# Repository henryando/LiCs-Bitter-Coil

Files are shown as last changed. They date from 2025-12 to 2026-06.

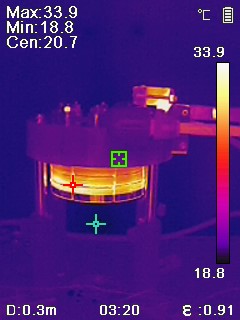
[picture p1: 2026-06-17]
ThermalImages/2026-03-30 New C1/IMG20260330032043.jpeg

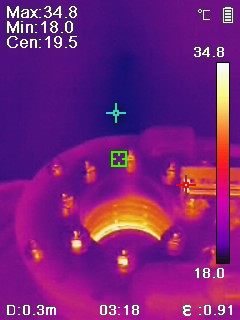
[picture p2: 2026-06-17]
ThermalImages/2026-03-30 New C1/IMG20260330031851.jpeg

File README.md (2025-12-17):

# LiCs-Bitter-Coil
Design files and instructions for Bitter coils built in the LiCs experiment in Chin Lab @ UChicago. 

The key authors of the files in this repository are Henry Ando, Leon Gold, and Cheng Chin. This repository is intended as an informational resource for the cold atom community. At the moment, it contains the following:

1. A PDF assembly guide written by Leon Gold, which outlines the key steps in our assembly process.
2. A folder containing all the CAD files for the coil we built. We designed it in Autodesk Fusion 360, so the 3D files are in that format. I have also included minimal 2D drawings, which are mostly for reference.
3. A draft of a manuscript describing the more general improvements we plan to make.

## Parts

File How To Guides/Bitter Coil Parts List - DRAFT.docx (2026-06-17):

# NEEDS UPDATE

# Full parts list

## Coil stack

- Bottom CuCr Disk x1
  - Machined by 3ERP out of C182 (CuCr alloy)
  - Immediately before assembly, cleaned with hot acetic acid
- Copper discs (normal) x30
  - Waterjet in house
  - From 0.04" thick 101 copper sheet, PN 89675K736 (https://www.mcmaster.com/89675K736)
  - Sanded with grits 220, 400, 600, 1200, 2000
  - Immediately before assembly, cleaned with hot acetic acid
- Copper disc (top) x1
  - Waterjet in house
  - From 0.04" thick 101 copper sheet, PN 89675K736 (https://www.mcmaster.com/89675K736)
  - Sanded with grits 220, 400, 600, 1200, 2000
  - Immediately before assembly, cleaned with hot acetic acid
- Copper connecting wedges x31
  - Waterjet in house
  - Leave tabs so they don’t fall off
  - Sandwich between two sheets of aluminum (89015K37 (https://www.mcmaster.com/89015K37)) so they don't completely warp, then use the thickness of the resulting sandwich in the waterjet settings
  - File off the tabs with the file side to side, i.e. along the axis of the tab, slowly and gently.
  - Made from 9014K174 (https://www.mcmaster.com/9014K174/), the shim stock is important because it has a much better thickness tolerance.
  - Sanded with grits 600, 1200, 2000. Sand lightly so you don't wear down the thickness too much.
  - Immediately before assembly, cleaned with hot acetic acid
- Polyester spacers x31
  - Laser cut in house
  - From 0.01" thick brown shim stock, PN 9513K119 (https://www.mcmaster.com/9513K119)
  - Use the PETG setting, 0.01" thick on the laser cutter
- Polyester spacer top x1
  - Laser cut in housee
  - From 0.01" thick brown shim stock, PN 9513K119 (https://www.mcmaster.com/9513K119)
  - Use the PETG setting, 0.01" thick on the laser cutter
- Silicone banana gaskets x94
  - Laser cut in house
  - From 0.02" thick high-temperature silicon rubber strips, durometer 40A (medium soft), PN 5344N113 (https://www.mcmaster.com/5344N113)
  - Use the silicone setting, 0.02" thick on the laser cutter
  - Note that the silicone pieces tend to fly away due to exhaust wind!
  - After cutting, sonicate in water then rinse in a strainer
- Silicone circle gaskets x64
  - Laser cut in house
  - From 0.02" thick high-temperature silicon rubber strips, durometer 40A (medium soft), PN 5344N113 (https://www.mcmaster.com/5344N113)
  - Use the silicone setting, 0.02" thick on the laser cutter
  - Note that the silicone pieces tend to fly away due to exhaust wind!
  - After cutting, sonicate in water then rinse in a strainer

## Compression screw system

- Stainless steel compression screw x7
  - Machined by 3ERP out of 316 stainless steel
- CuCr Screw x1
  - Machined by 3ERP out of C182 (CuCr alloy)
  - Path: RevisedManufacturing20231107/MachineParts/Steel-Compression-Rod.step
  - Immediately before assembly, cleaned with hot acetic acid. I think sanding will only hurt, the surface finish from 3ERP rocks
  - Note for future: make the groove in the top a bit deeper and/or make something stick off the top that you can grab with a wrench, the slot I milled this time is a bit thin and wore out quick under stress.
- O-rings x8
  - Chemical-Resistant Viton® Fluoroelastomer O-Ring 1/8 Fractional Width, Dash Number 202, PN 9464K118 (https://www.mcmaster.com/9464K118)
- Top washers (many, at least 24)
  - 316 Stainless Steel Washer for 1/4" Screw Size, 0.281" ID, 0.625" OD, PN 90107A029 (https://www.mcmaster.com/90107A029)
- Nuts for top of steel screws
  - 316 Stainless Steel Hex Nut, 1/4"-28 Thread Size, 94804A305 (https://www.mcmaster.com/94804A305)
- Nut for CuCr screw x1
  - 316 Stainless Steel Thin Hex Nut, Super-Corrosion-Resistant, 5/16"-24 Thread Size, 94805A213 (https://www.mcmaster.com/94805A213)
- Washers for CuCr screw (at least 3-4)
  - 316 Stainless Steel Washer for 5/16" Screw Size, 0.344" ID, 0.75" OD, 90107A030 (https://www.mcmaster.com/90107A030)

## 3D printed piece & water system

- 3D printed piece
  - Printed in SLA "High Temperature Resin" by a company we found through CraftCloud, called 3DPnxt
  - OR maybe printed in SLA "Surgical Guide Resin" this is the recommendation from Shaozhen!
- NPT tap
- Vibra-TITE 481 Plastic Thread Sealant 70 mL (https://www.amazon.com/gp/product/B09GWBD2XG/)
- Plastic NPT to push-to-connect fitting (https://www.usplastic.com/catalog/item.aspx?itemid=30737)
- Vacuum chamber screws
  - Ours are probably 1/4-20 or 1/4-28

## Bus bar system

- Bus bar top
  - C101
  - Machined by 3ERP
  - Immediately before assembly, cleaned with hot acetic acid
- Bus bar bottom
  - C101
  - Machined by 3ERP
  - Immediately before assembly, cleaned with hot acetic acid
- Top bus bar bracket
  - Machined by 3ERP
- CuCr screw
  - Machined by 3ERP
- Plastic separator x1
  - Laser cut in house
  - 0.01" brown plastic shim stock
- O ring x1
  - Chemical-Resistant Viton® Fluoroelastomer O-Ring, 3/32 Fractional Width, Dash Number 108
  - 9464K113 (https://www.mcmaster.com/9464K113)
  - Note this is DIFFERENT than the other ones
- Tube fittings x2
  - Push-to-Connect Tube Fitting for Air and Water, Nickel-Plated Adapter, for 1/4" Tube OD, 1/16 NPT Male
  - 7880T123 (https://www.mcmaster.com/7880T123)
- Countersunk 2-56 nylon screws, 3/4" long, x2
  - PN 92929A120 (https://www.mcmaster.com/92929A120)
- Simple 2-56 nylon screws, 1" long, x6
  - 94613A086 (https://www.mcmaster.com/94613A086)
- Bus bar mounting screws: 6-32, 7/8" long, x6
  - 92185A152 (https://www.mcmaster.com/92185A152)
- Top bus bar bracket screws x2
  - 1-1/8" long, 316 stainless steel
  - PN 92185A154 (https://www.mcmaster.com/92185A154)
- Bottom bus bar bracket screws x2
  - 1-5/8" long, 316 stainless steel
  - PN 92185A174 (https://www.mcmaster.com/92185A174)
- Lug screws
  - 1/4"-20 Thread Size, 1/2" Long
  - PN 93190A537 (https://www.mcmaster.com/93190A537)
- Lug washers
  - 1/4" washers

## Assembly props

- Steel dowels 1/4" x 3"
  - PN 98381A554 (https://www.mcmaster.com/98381A554)
- Clamp jaws, top and bottom
  - Make out of random scrap from machine shop
  - Or ask DeMille lab to borrow?

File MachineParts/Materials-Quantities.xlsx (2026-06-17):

Part | Material | Quantity
Bus-Bar-Bottom.step | C101 | 2
Bus-Bar-Top.step | C101 | 2
CuCr-Compression-Rod.step | C182 | 2
CuCr-Disk.step | C182 | 2
CuCr-Rod-Bracket-A.step | C360 | 2
CuCr-Rod-Bracket-B.step | C360 | 2
Steel-Compression-Rod.step | SS316 | 15
Top-Layer-Bracket.step | C360 | 2

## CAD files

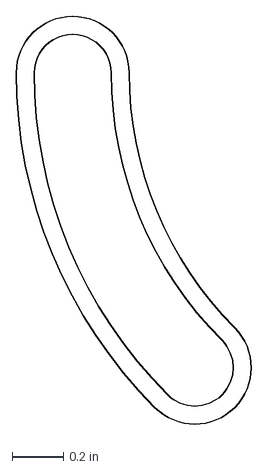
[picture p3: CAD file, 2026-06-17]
LasercutParts/Modified-Banana-Gasket.dxf
0.937 x 1.61 in

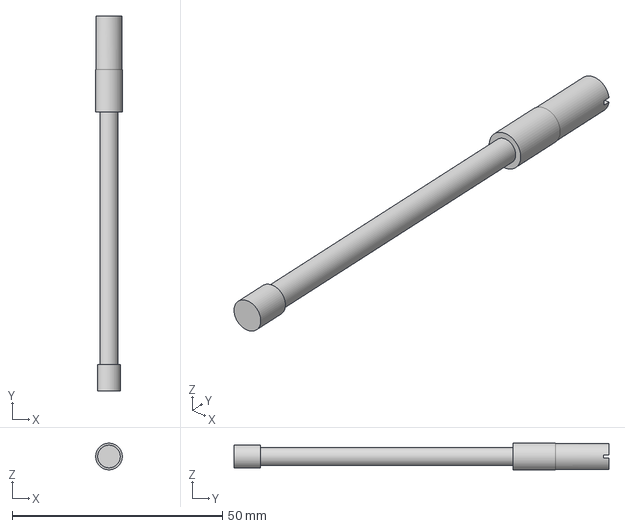
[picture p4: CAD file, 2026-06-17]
MachineParts/Steel-Compression-Rod.step
6.34 x 89.2 x 6.35 mm

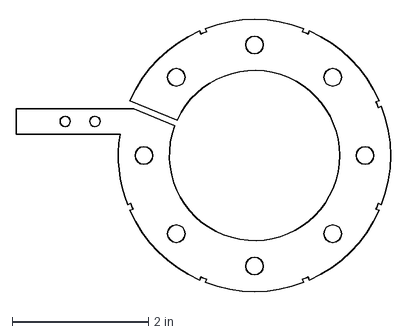
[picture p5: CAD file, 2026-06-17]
WaterjetParts/Copper-Disc-Top-2025mod.dxf
5.55 x 4.09 in

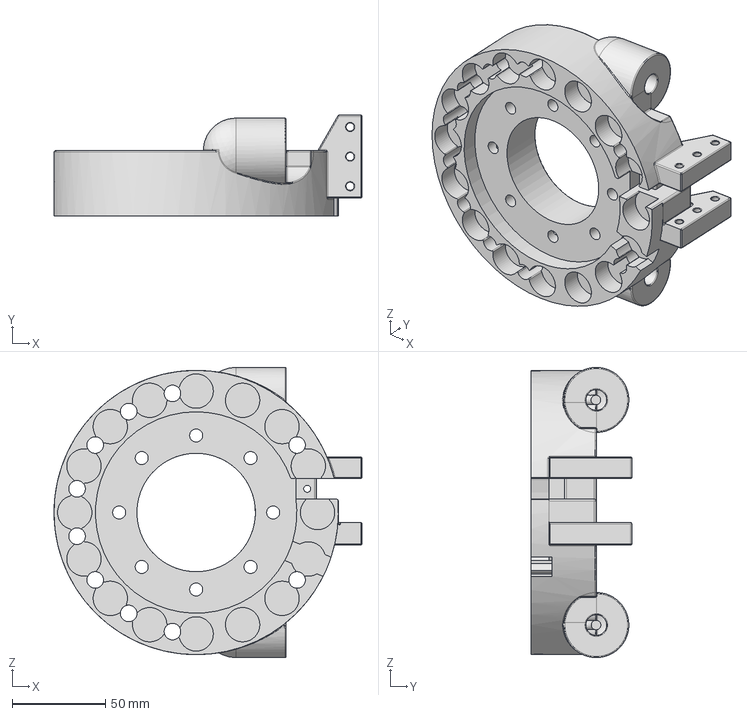
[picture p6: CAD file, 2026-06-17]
3DPrintedParts/Water-Distribution-Block v30.step
165.1 x 54.0 x 155.6 mm

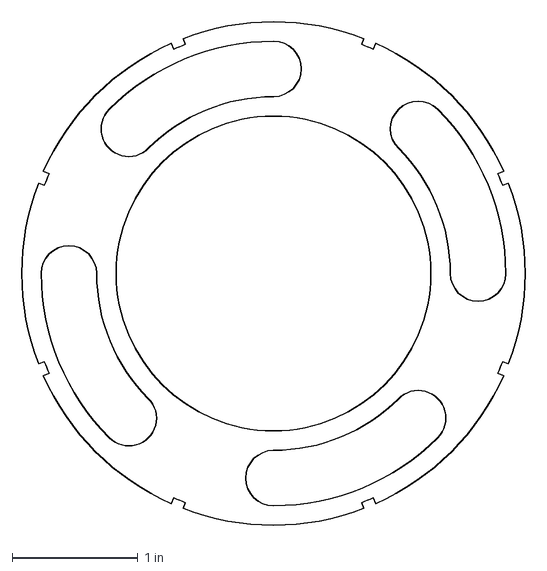
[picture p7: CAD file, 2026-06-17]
LasercutParts/Modified-Poly-Spacer-Top.dxf
4.09 x 4.09 in

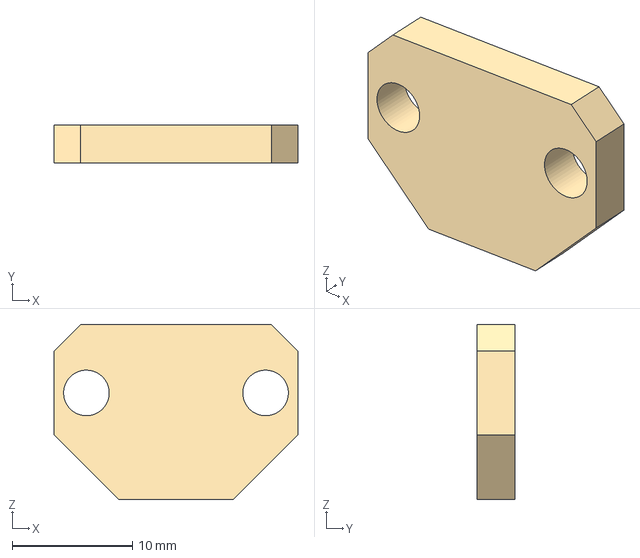
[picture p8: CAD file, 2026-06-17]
MachineParts/CuCr-Rod-Bracket-B.step
20.3 x 3.17 x 14.6 mm

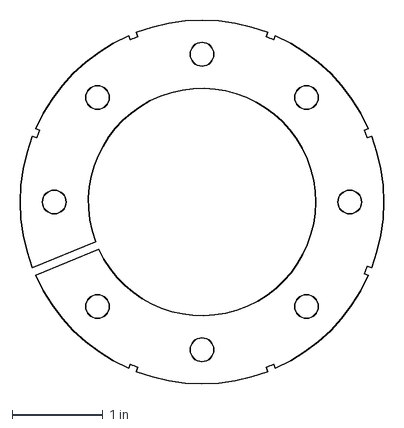
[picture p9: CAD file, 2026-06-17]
WaterjetParts/Copper-Disc-Layer.dxf
4.09 x 4.09 in

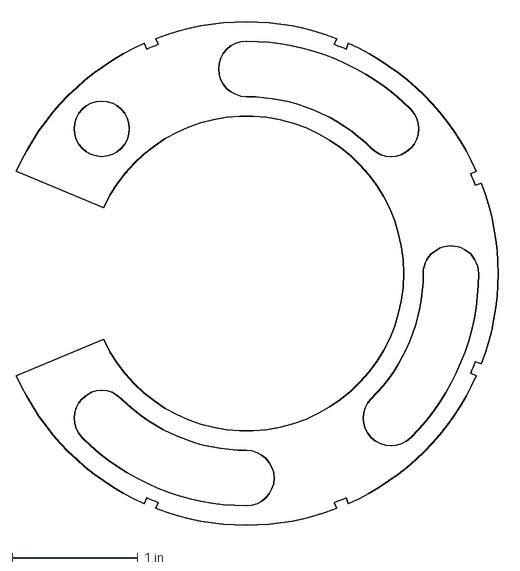
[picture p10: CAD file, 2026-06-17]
LasercutParts/Modified-Poly-Spacer.dxf
3.87 x 4.09 in

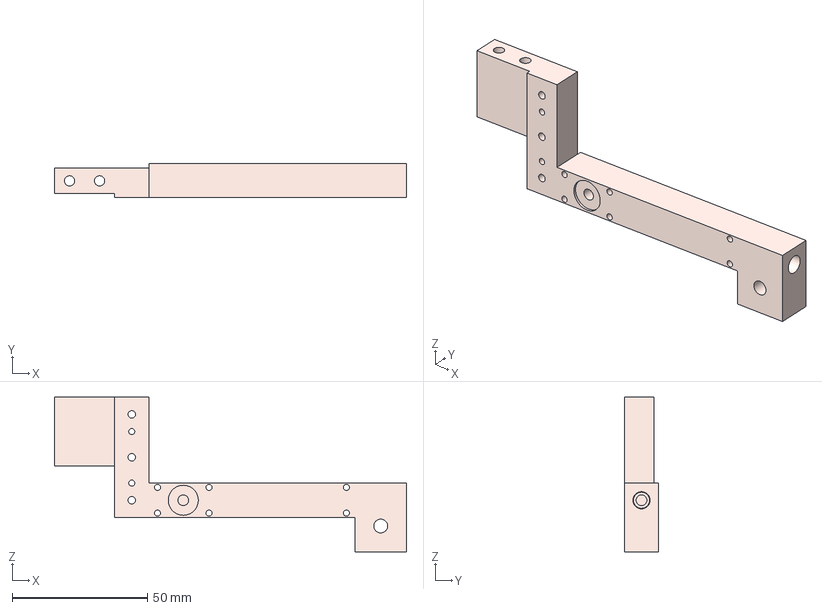
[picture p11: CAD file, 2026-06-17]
MachineParts/Bus-Bar-Top.step
130.2 x 12.7 x 57.1 mm

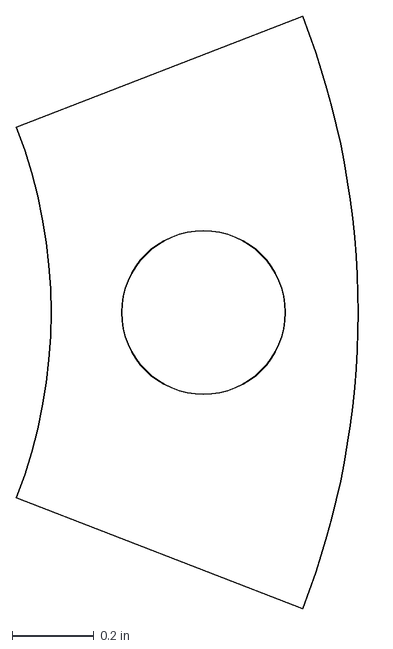
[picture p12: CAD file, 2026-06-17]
WaterjetParts/Copper-Wedge.dxf
0.88 x 1.45 in

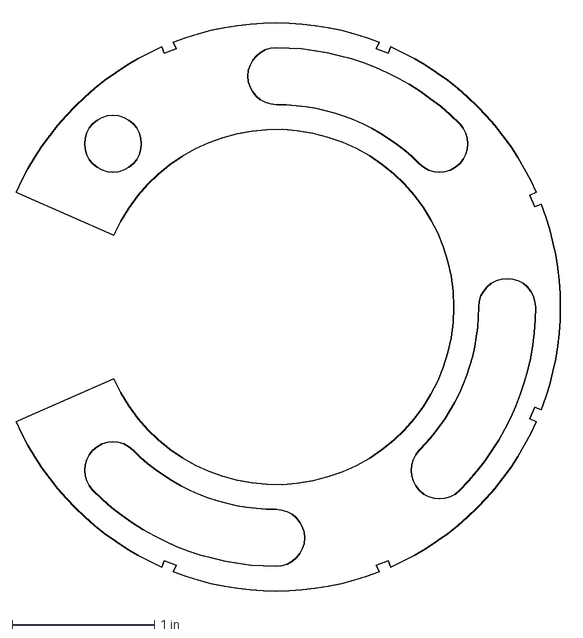
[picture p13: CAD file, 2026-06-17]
LasercutParts/Poly-Spacer.dxf
3.88 x 4.09 in

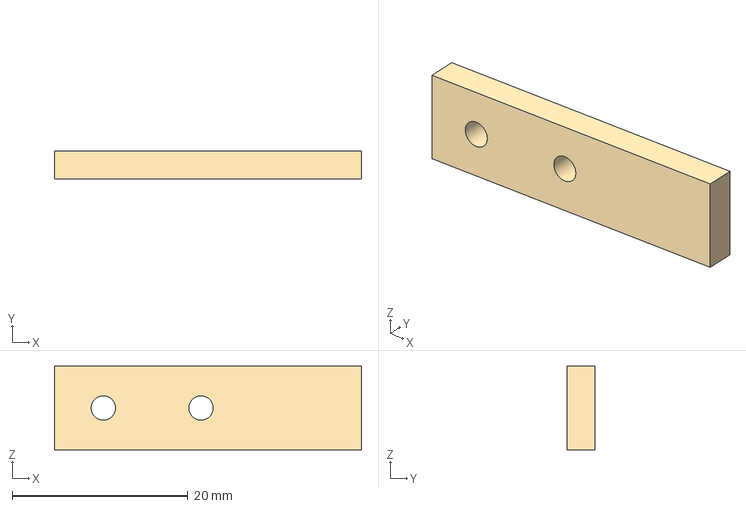
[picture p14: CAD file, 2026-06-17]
MachineParts/Top-Layer-Bracket.step
34.9 x 3.17 x 9.52 mm

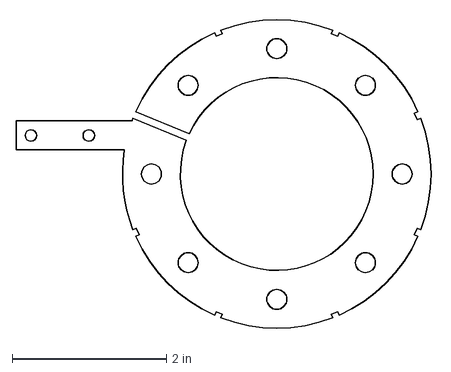
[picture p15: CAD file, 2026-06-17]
WaterjetParts/Copper-Disc-Top.dxf
5.42 x 4.09 in

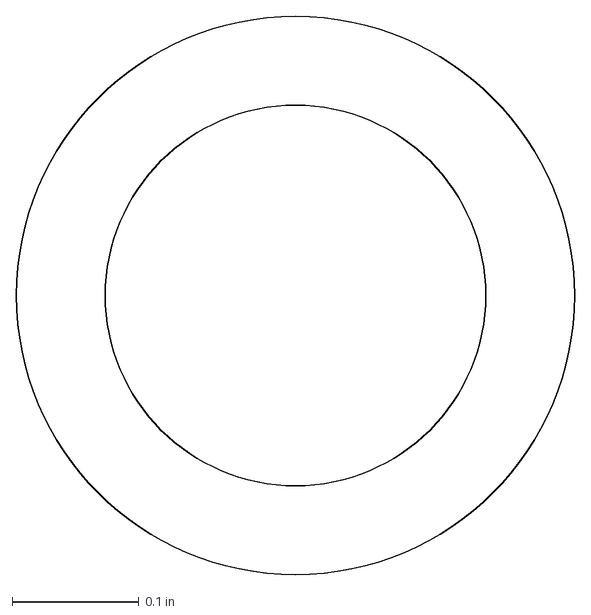
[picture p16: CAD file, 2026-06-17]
LasercutParts/Modified-Circle-Gasket.dxf
0.44 x 0.44 in

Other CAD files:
MachineParts/CuCr-Rod-Bracket-A.step
WaterjetParts/Modified-Copper-Wedge.dxf
LasercutParts/Bus-Bar-Poly-Spacer.dxf
MachineParts/Bus-Bar-Bottom.step
3DPrintedParts/Water-Distribution-Block v15.step
3DPrintedParts/Water-Distribution-Block v16.step
3DPrintedParts/Water-Distribution-Block v27.step
3DPrintedParts/Water-Distribution-Block v30.f3d
3DPrintedParts/Water-Distribution-Block v5.step
3DPrintedParts/Water-Distribution-Block v6.step
MachineParts/CuCr-Compression-Rod.step
MachineParts/CuCr-Disk.step

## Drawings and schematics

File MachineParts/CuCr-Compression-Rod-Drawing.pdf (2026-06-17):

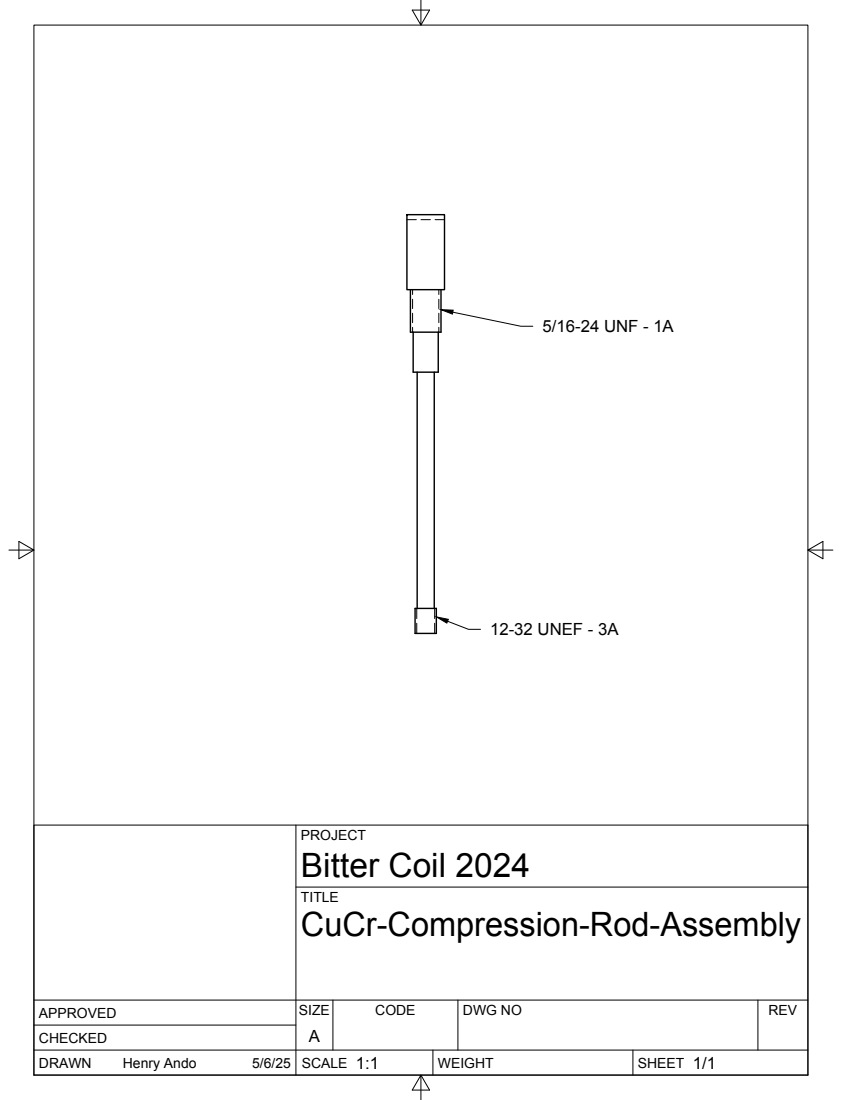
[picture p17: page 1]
SIZE; CODE; DWG NO; REV; Henry Ando; 12-32 UNEF - 3A; 5/16-24 UNF - 1A

PROJECT
Bitter Coil 2024
CuCr-Compression-Rod-Assembly

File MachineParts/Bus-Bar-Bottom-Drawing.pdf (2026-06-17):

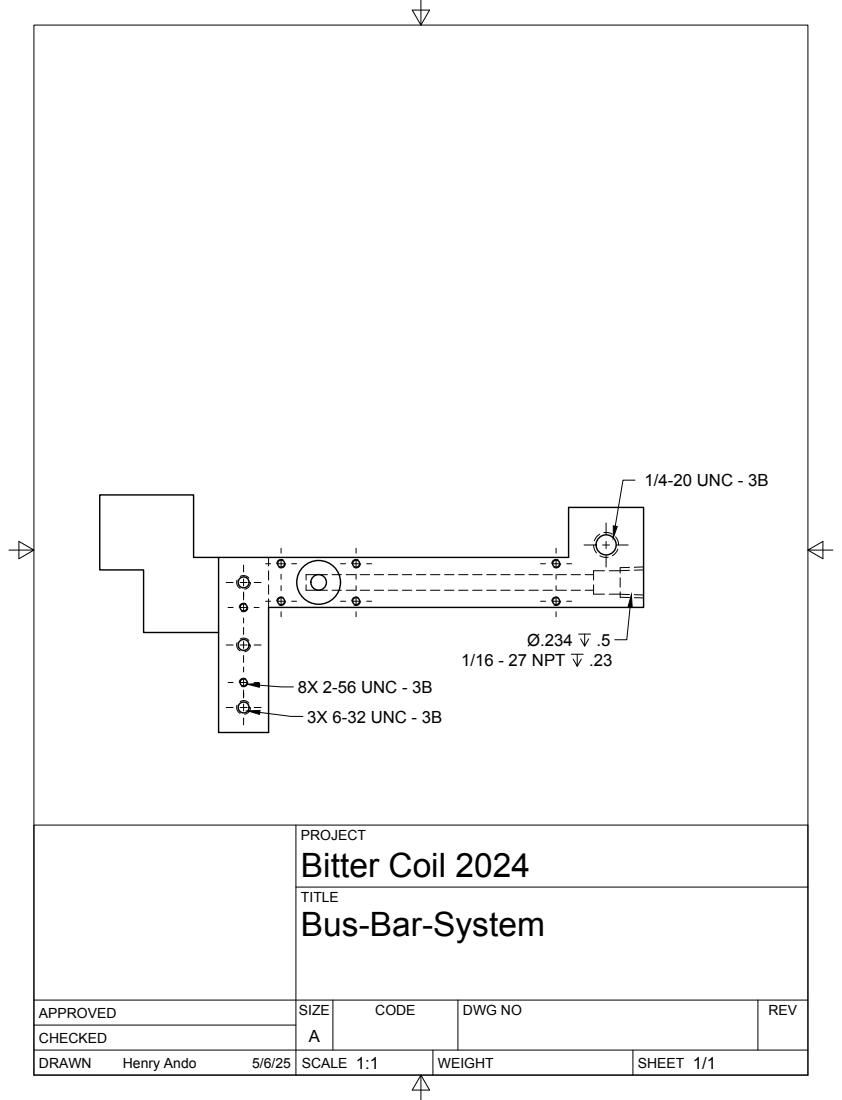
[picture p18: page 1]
SIZE; CODE; DWG NO; REV; Henry Ando; 3X 6-32 UNC - 3B; 8X 2-56 UNC - 3B; 1/4-20 UNC - 3B; 1/16 - 27 NPT

PROJECT
Bitter Coil 2024
Bus-Bar-System

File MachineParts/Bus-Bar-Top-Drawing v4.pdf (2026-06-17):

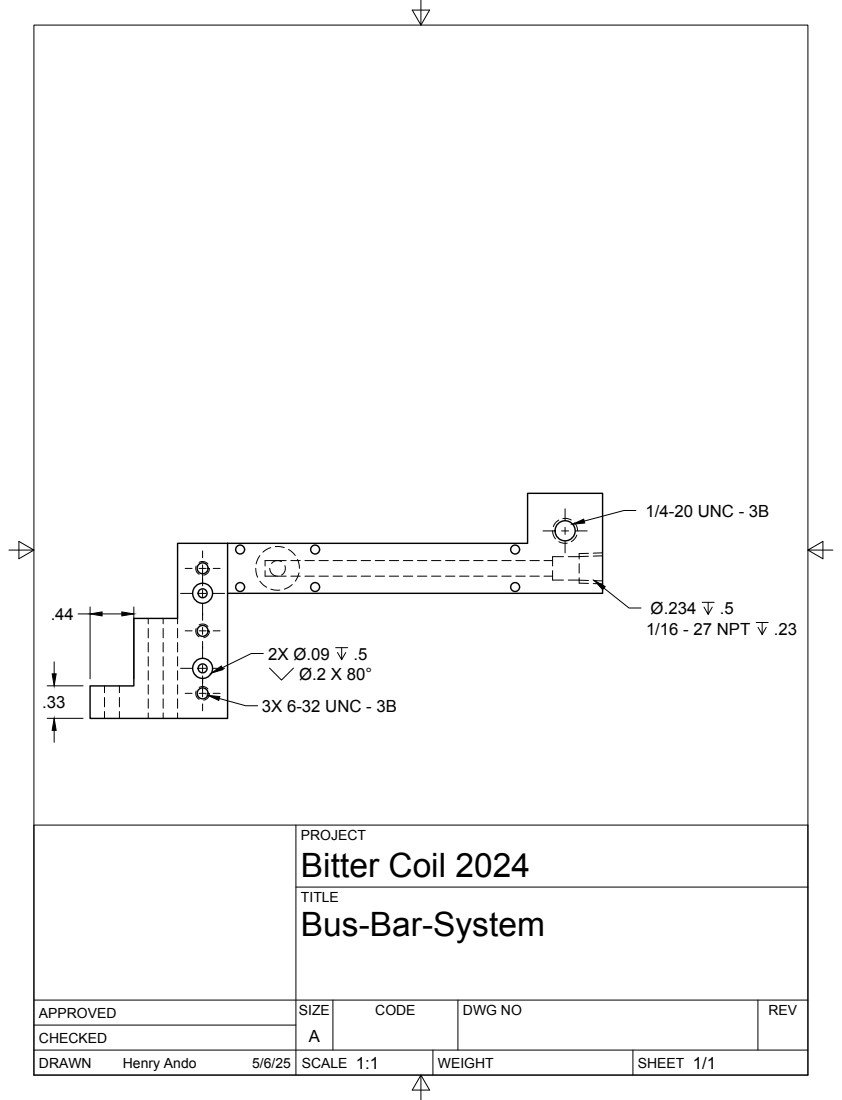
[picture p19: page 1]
SIZE; CODE; DWG NO; REV; Henry Ando; 1/4-20 UNC - 3B; 3X 6-32 UNC - 3B; 1/16 - 27 NPT

PROJECT
Bitter Coil 2024
Bus-Bar-System

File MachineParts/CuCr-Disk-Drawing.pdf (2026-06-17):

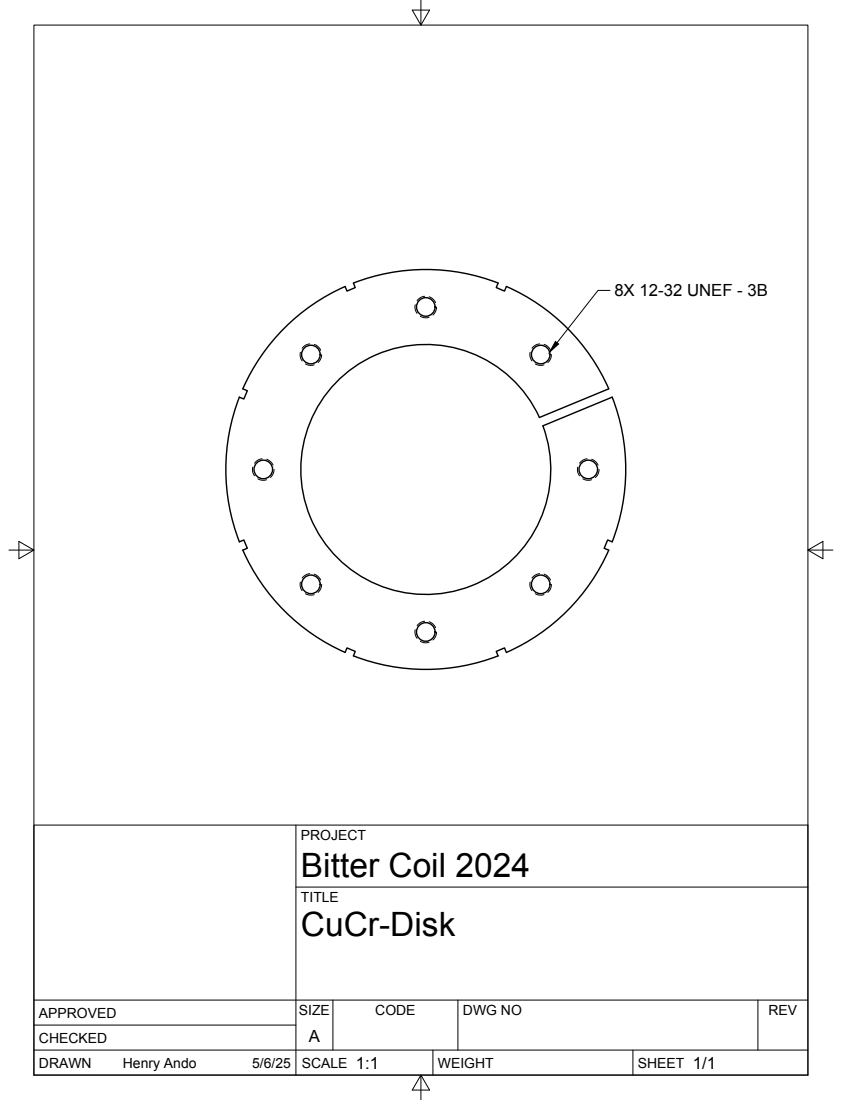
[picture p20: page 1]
SIZE; CODE; DWG NO; REV; Henry Ando; Bitter Coil 2024; 8X 12-32 UNEF - 3B

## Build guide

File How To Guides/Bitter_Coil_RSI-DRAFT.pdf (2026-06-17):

## Design Principles for Cold Atom Bitter Coils - DRAFT

Henry Ando,¹ Leon Gold,¹ Geyue Cai,¹

and Cheng Chin¹
The James Franck Institute, Enrico Fermi Institute, and Department of Physics, The University of Chicago, Chicago, Illinois 60637, USA

(Dated: 17 December 2025)

We present the design, construction, and characterization of a novel design for Bitter-type electromagnets that can generate large magnetic fields with efficient heat removal for cold-atom experiments. The new design, based on the design presented by Sabulsky et al. 2013, presents an improved and more durable cooling system, and significant reductions in peak thermal resistance, allowing for the safe generation of high magnetic fields with minimal risk of experimental damage from the electromagnets. The electromagnets are constructed from a stack of alternating layers of copper arcs and insulating polyester spacers. Efficient cooling is achieved via perpendicular water cooling channels distributed by a heat-resistant resin block. This ensures that a large portion of the electromagnet is in contact with water cooling, ensuring efficient energy dissipation. Using silicone gaskets and compression, a watertight seal is created, allowing easy disassembly and reassembly of the coil if necessary. At the location of the atoms in our LiCs experiment, 17 mm from the coil’s base, the coil has a 1.62 G/A ratio. With 1.28 gal/min cooling water at a temperature of 14oC applied, the coil body heats by 12.2oC under continuous operation at 330 A to a temperature of 28.2oC, with the heat of all components kept below 29oC.

I. INTRODUCTION

Cold-atom experiments require (a) large magnetic fields,
(b) the ability to quickly adjust them (low inductance), and
(c) thermal stability.
The most common approach to generate these fields is a wound hollow-core wire coil¹⁻³. Recently, other machined geometries have been explored, including Bitter-type electromagnets³,4
Bitter coils have two key advantages over hollow-core wire coils: (1) The water cooling is in parallel with the current, so the temperature is more uniform across the coil, and (2) the hydrodynamic resistance of a Bitter coil is much lower than that of a hollow-core wire coil, reducing the need for highpressure pumps and corresponding vibration concerns associated with them.
Previously, we reported on the construction of a bitter coil for cold atom experiments³
. After a decade of use, we have identified two primary issues with the original design.
(1) The electrical contact resistance in the bolts that carry the current into and out of the primary coil winding tends to creep upward with time, causing extreme heating, and is then difficult to fix due to access limitations. (2) The plastic water distribution manifold is prone to cracking and leaking.
In this work, we report on a new version of this coil, which seeks to improve on these issues, while also leveraging modern manufacturing technologies such as waterjet cutting, laser cutting, and 3D printing. Our design modifications take inspiration from many other groups⁵,6, particularly the excellent work by Siegel et al. at NIST⁷
Our new approach to the current delivery system seeks to reduce heating and improve maintainability by replacing threaded current-carrying connections with flat, accessible surfaces and by water cooling every current-carrying element of the system.
Our new 3D printed water distribution manifold seeks to reduce the likelihood of cracks by reducing the total number of incoming/outgoing water connections from 8 to 2, and by eliminating any threads tapped into plastic, with external tubes mated to compression fittings.

With these improvements, we reduce the maximum temperature increase when producing 1000 G ( 320 A, 780 W per coil) to under 29 oC, and verify that the water distribution manifold is robust to 2000 full thermal cycles.

II. CURRENT DELIVERY SYSTEM

The main electrical issues we’ve encountered with the original version of the coil have to do with the connections between the bus bars and the coil stack itself.
In the original design, a current-carrying screw carried current from the bottom layer of the coil to the outgoing bus bar. The full current then passes through the threads of the screw into a copper block. This electrical connection proved problematic over time, as thermal cycling and oxidation gradually caused a runaway increase in contact resistance. Undoing this connection to clean and deoxidize coil surfaces is impossible because the connection in question also provides the clamping force that holds the coil together and the water in.
Another problematic connection was where current was carried from the incoming bus bar into the second current-carrying screw through the threads, then passed into the copper distribution block through the tip of the screw. Both of these connections also developed high contact resistances over time. Since the copper distribution block was recessed, our ability to clean and polish its surface to improve the contact resistance was minimal.
In the updated design, the direction of the compression bolts is reversed: they are installed from the water distribution block downward into blind-tapped holes in the bottom plate. This enables us to separate the mechanical and electrical roles of the current-carrying screw. Now, a nut provides mechanical compression on the coil while the electrical connection is made by a flat surface clamped securely onto the bus bar. Thus, the bus bar can be removed and the connection cleaned, without breaking the water seal. And should the threaded connection between the current-carrying screw and the bottom plate need to be serviced, the blind taps allow the current-carrying screw to be removed through the top of the

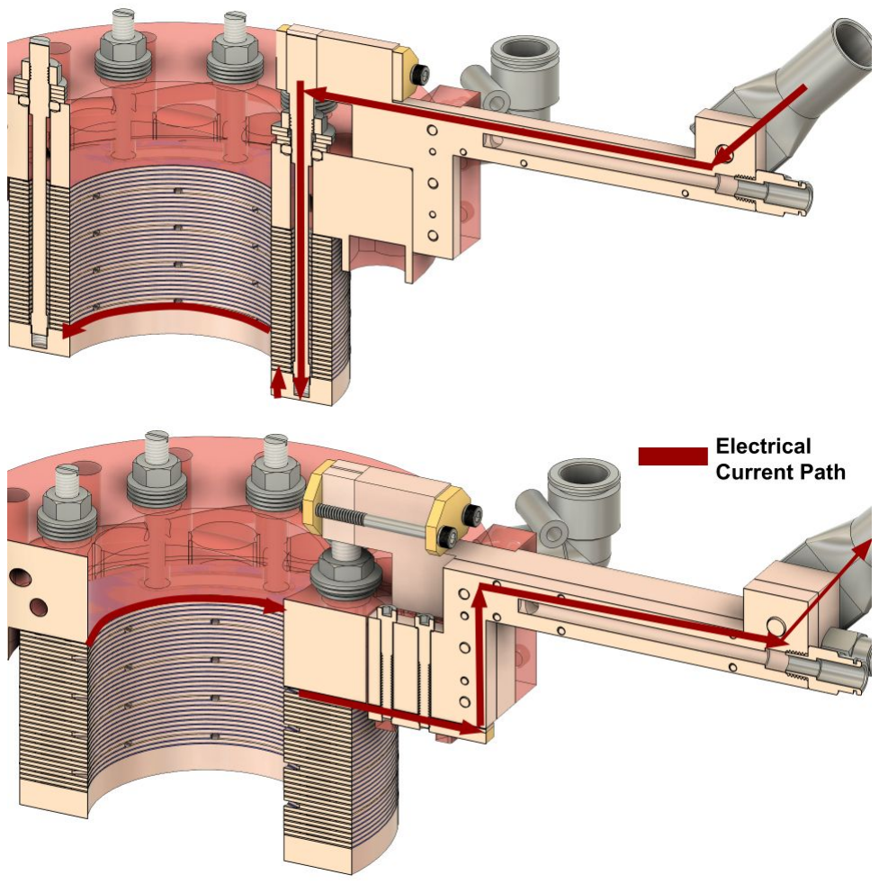
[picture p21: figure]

FIG. 1: The current delivery system to the coil, with current brought from a power supply through a water-cooled bus bar, to the base of the coil via its contact with a conducting copper screw, through the coil, and back to ground via the top of the coil’s connection with the other water-cooled bus bar.

water distribution block without creating a leak at the bottom of the coil.
Meanwhile, the connection between the incoming bus bar and the top layer of the coil is now made directly, by adding a tongue of metal to the top layer, which is clamped to the bottom of the incoming bus bar. The contact area here is much greater than before, and the bus bar can be removed and all relevant surfaces cleaned/deoxidized if need be, without creating any leaks.
Another general improvement in the new design is that all parts serving both electrical and mechanical purposes (which were previously made of brass) we now make out of chromium-copper C182, inspired by the NIST group⁷
. C182
has twice the electrical conductivity of brass while also being stronger and more chemically similar to copper.
The bus bars can get hot, as hot as 40oC when 330 A are applied to the coil, which is why the bus bars are water cooled in parallel with the cooling water going to the coil, although the source is from the same chiller. The bus bars are cooled via internal water cooling cavities installed, connected via a rubber o-ring, and held together via Nylon screws, with the water connectors fitting into NPT taps in these cavities.

III. WATER DISTRIBUTION SYSTEM

The primary issue encountered with the water distribution system in the past was leaks. Leaks mainly occur when the plastic around an NPT-tapped pipe fitting cracks. Once a crack forms, little can be done to remedy the problem in the long term. Common plumbing wisdom advises avoiding plastic/metal pipe connections, especially when a metal male fitting is installed into plastic female threads. This is because plastic is much weaker than metal, especially under tension. Moreover, plastic and metal have different coefficients of thermal expansion, so with thermal cycling, the metal fittings expand and contract relative to their plastic sockets, gradually

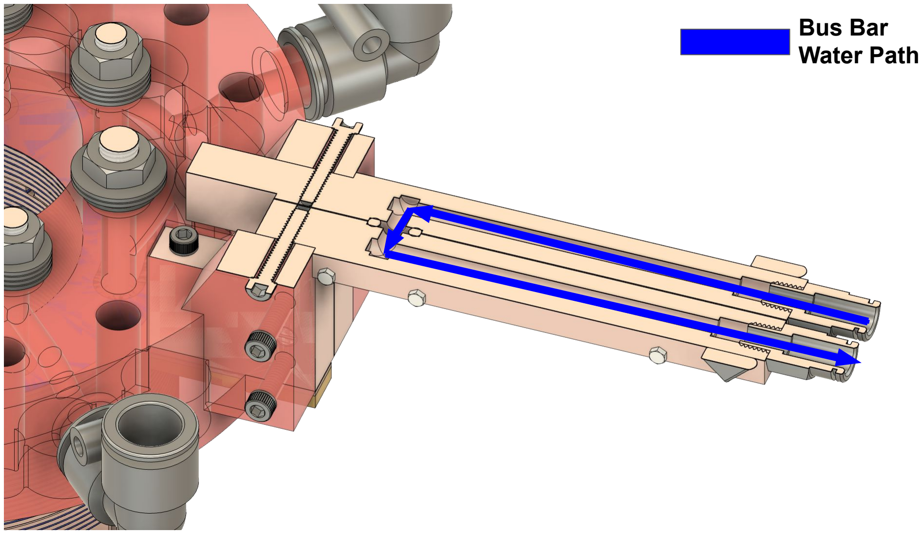
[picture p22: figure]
Bus Bar Water Path

FIG. 2: The water cooling system for the bus bars, that cool the bus bars in parallel with the coil, so that the temperature rise at 330 A remains below 28 oC at 330 A. This water cooling system in its present configuration brings 0.47 gal/min through the bus bars.

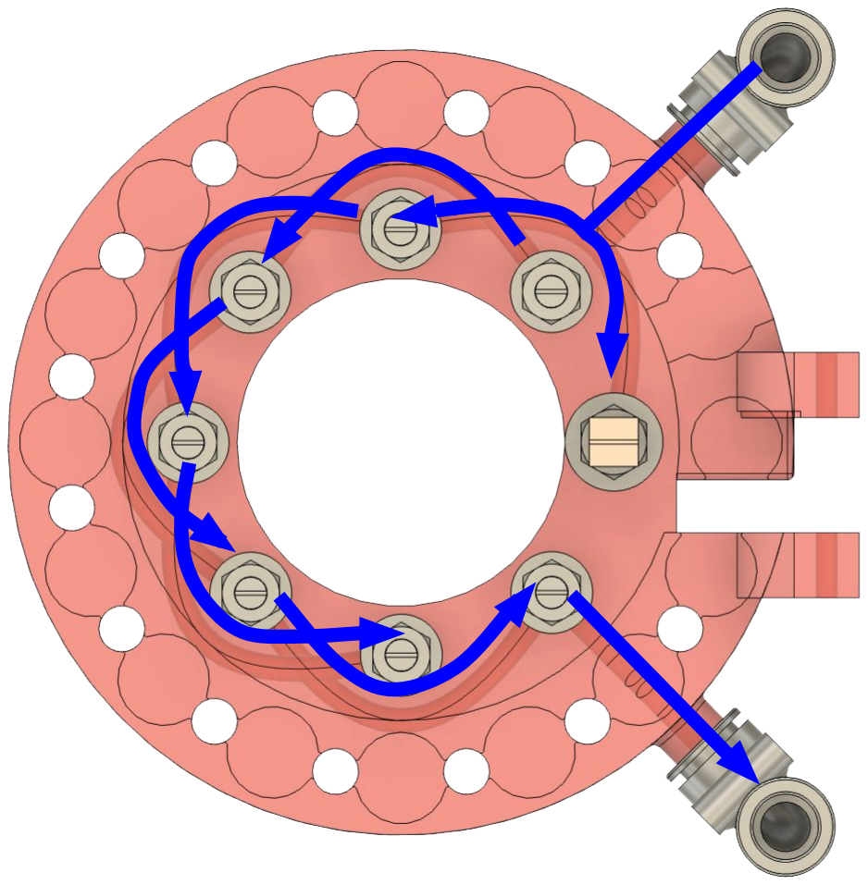
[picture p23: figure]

FIG. 3: A top view of the coil’s cooling block made out of high temperature resin, with two layers of interior tubing bringing water into and out of the coil through one inlet and one outlet. With our current chiller, 1.28 gal/min can be put through the coil.

stressing the material until it eventually cracks.

The prior design was more prone to leaks with its four water inlets and four outlets, due to geometry limitations imposed by the limits of traditional machining.

In the new design, we leverage the capabilities of 3D printing to address both of the above issues. 3D printing the water distribution block allows us to reduce the number of water inlets and outlets from four each to one each, by routing the water between the vertical channels through internal 3D printed water channels. This technique was also used by the NIST group⁷

We also remove the need to screw male NPT fittings into female plastic threads by 3D printing an external 0.5” diameter tube, onto which a normal push-to-connect tube fitting can be installed without modification. This eliminates any tensile strain on the plastic piece. Credit for this idea goes to Shaozhen Yang and Rohan Kapur from David DeMille’s group⁵

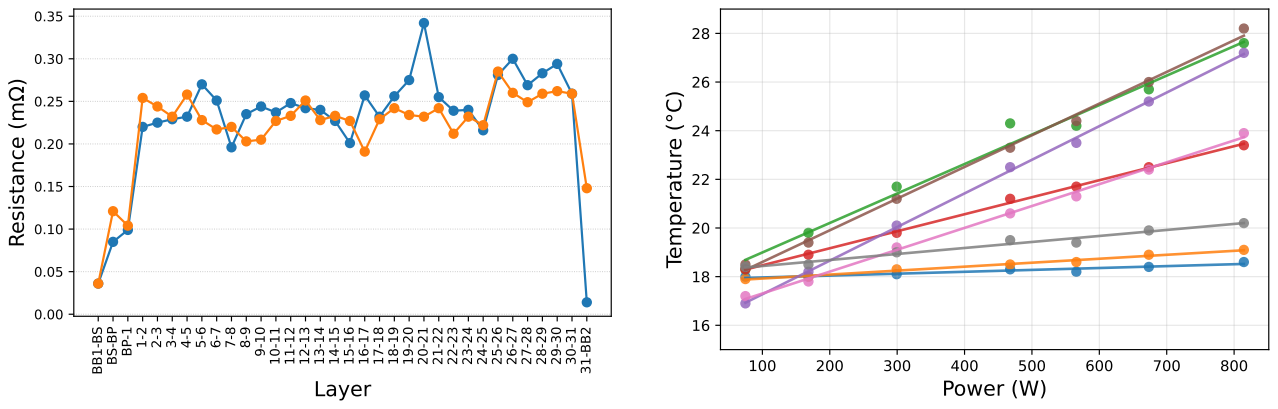
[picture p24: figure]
Layer; Resistance (m ); Power (W); Temperature (°C)

FIG. 4: Electrical resistance between successive coil parts in units of mΩ. The blue line represents the first coil we made (coil 1), and the orange line represents the second coil we made (coil 2). Here, BB1 represents the bus bar connected to the incoming current, BS denotes the conducting screw, and BP refers to the baseplate.

IV. RESULTS

After assembling the latest coil version, we obtain an operational profile by measuring the magnetic field, electrical resistance, inductance, and thermal characteristics during operation.
The electrical resistance of the coil was measured with a voltmeter between the bus bar connected to the incoming current and successive coil layers to obtain a layer resistance profile, while a constant current of 1 amp was applied.
The electrical resistance of the coil can be mathematically estimated from the equation.

R = 2πNρ0
dλ ln
a2
a1

where N = 31 is the number of turns, d = 1 mm is the thickness of a copper arc, a1 = 31.75 mm is the inner radius of the electromagnet, a2 = 50.80 is the outer radius, λ = 0.77 is the filling factor, and ρ0 = 1.7 ∗ 10⁻⁸Ωm is the resistivity of copper. This yields a theoretical resistance of 7.56mΩ.
The theoretical value matches closely the electrical resistance observed of 7.6 (1) mΩ. This is lower than the resistance in the prior coil by 1.1 mΩ.
The reduction in total resistance from 8.71 mΩ down to 7.6(1) mΩ is significant, and this reduction is likely due to a better coil-to-current connection, with these bus bars having minimal contact resistance and better compression techniques. As shown in Fig 4, the layers of the coil account for approximately 95% of the total resistance of the coil, suggesting that much of the resistance attributed to the bus bars from the prior design has been removed and that the new coil is close to the theoretical resistance for this coil design of 7.56 mΩ.
To characterize the thermal resistance of the current design, the temperature was measured at 6 points on the coil using thermistors. One sensor was placed on each bus bar, the input and output tubes, the Copper-182 screw, the Copper-182 Plate at the base of the coil, and the Coil Body. The temperature was
measured as the current passing through the coil was gradu- | 100 | 200 | 300 | 400 | 500 | 600 | 700 | 800

FIG. 5: Temperature of coil components at different power levels. Blue represents the inlet tube, gray the outlet tube, orange the incoming-current bus bar, green the outgoing-current bus bar, red the current-carrying screw, purple the baseplate, brown the lower coil, and pink the upper coil.

ally increased from 0 to 330 amps. During this measurement, the water flow rate was 4.84 L/min into the coil body and 1.8 L/min into the bus bars.
Figure 5 shows the temperature at different coil components as a function of power applied to the coil, with the coil being cooled by 14 o water supplied at a constant flow rate of 1.6 gallons per minute. It demonstrates that the maximum temperature change for 20.7◦C at 330 A, which is shown in one of the Bus Bars, which heated from 20.3 to 41.2◦C. Due to access limitations we don’t have a perfectly analogous number for the existing coils installed in our experiment, but a probe on the bus bar of one coil suggests that it regularly reaches 41.2 ◦C running 330 A at a 50% duty cycle with a similar water flow rate.
The input water was measured to have a temperature of approximately 14.0oC, although the tube warmed by 2.4 oC as the current increased to 330 A. The output water was warmer by 2.6 oC. The lower coil body increased in temperature by 12.7◦C from 15.5◦C to 24.0◦C. The coil baseplate made of Copper-182 increased in temperature by 5.9 degrees from 16.0◦C to 21.9◦C. These components were the parts of the coil kept the most cool, due to high exposure to the cooling water, as part of the cooling system design. The head of the Copper-182 screw had an initial temperature of 19.1◦C, and as the coil increased to 330 A, the temperature rose by 12.2◦C to 31.3◦C. The bus bars started at respective initial temperatures of 20.5◦C and 20.3◦C and rose to 41.2◦C and 35.5◦C after the current was raised to 330 A.
We will briefly describe the magnetic field and inductance results. The magnetic field was tested inside and outside the coil using a gaussmeter, with the bottom of Copper-182 base of the coil used as a reference point.A constant current of 100.01 A was applied to the coil during the testing.
The theoretical field value of the coil at the location of the atoms was calculated to be 1.56(3) G/A. This was predicted from an equation calculating the magnetic field from the coil based on the distance from the bottom of the coil:

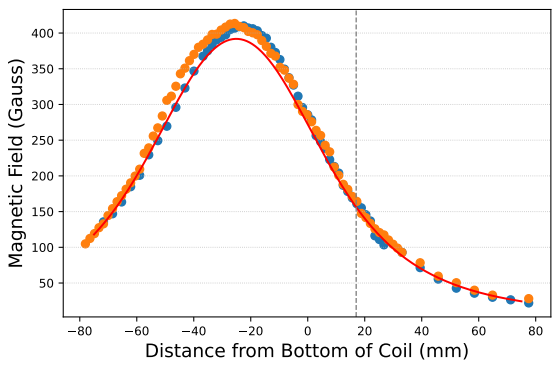
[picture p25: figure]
Distance from Bottom of Coil (mm); Magnetic Field (Gauss)

FIG. 6: Magnetic field of coils with 100.01 amps applied as a function from the distance to the bottom of the coil’s baseplate. The red line represents the simulation of the field described by the equation below. The blue data points represent the measured field of coil 1, and the orange data points represent the measured field of coil 2. The gray dashed line represents the location of the atoms 17 mm from the bottom of the coil.

Bz(z) =C∑

k=32
k=1

µ0dλ
2

·

I
dλ ln(a2/a1)
√

1
a

2
1+(z−zk

)

2 − √

1
a

2
2+(z−zk

)

2

where C is the correction constant of 7/8 reflecting that the current only goes 7/8 of the way around the coil, d is the thickness of an annulus, λ is the copper filling factor, I, a1 is the inner radius, a2 is the outer radius, z is the distance from the center of the coil, and zk

is the distance between the annulus and the coil bottom zk = zf ace + (k−1)d. where zf ace is the thickness of the base plate.
At 17 mm from the bottom of the coil, the distance between the bottom of the coil and the center of the Li-Cs science chamber, the total measured field had a value of approximately 1.59(3) G/A. The magnetic field was experimentally found by applying 100 A to the coil, and measuring the magnetic field at various distances from the bottom of the coil. A profile of the magnetic fields in both coils and the comparison to the simulated field based on the equation above is shown in figure 3, which shows that the measured field closely matches the simulated field.
The theoretical inductance of the coil can be derived from the equation³

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
. Here t is the half height of the coil, and Λ is the self inductance factor, which we found to be 15. This equation yields a theoretical inductance of 45.8 µH.
The impedance of the coil was measured using an oscilloscope from a circuit that applied a variable current to both the coil and a 10Ω resistor. The impedance was defined as the ratio of amplitudes between the resistor and the coil (divided by 10 to get it in standard units of Ohms). After graphing impedance we were able to estimate the inductance of the coil to be 42.6µH, which is 4.81 µH less than the measured value from the prior coil. It is also close to the theoretical inductance of 45.8 µH.

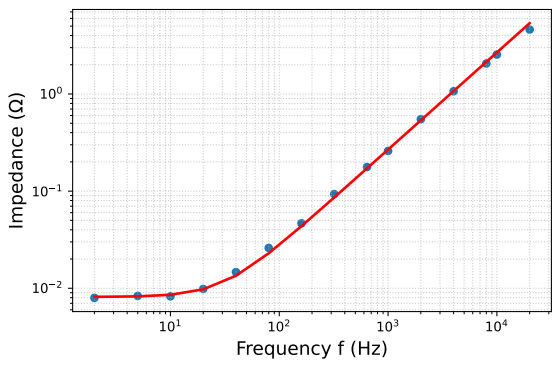
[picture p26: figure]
Frequency f (Hz); Impedance ( )

FIG. 7: The impedance of the coil at different applied frequencies, with the fits for resistance and inductance labeled. The data points represent the measured impedances, while the red line is the line of best fit, with the inductance at 42(1) µH and the starting resistance at 8.1(3) mΩ.

V. CONCLUSION

We have described a state of the art, simple, and scalable design of a Bitter electromagnet design for cold-atom experiments alongside other potential uses in industry or quantum computing. During high field operation the coil exhibits stable resistances, temperatures, inductances, and magnetic fields, and outperforms many peer electromagnets, including the prior design published from this group.
The new coil provides improved thermal, electrical, and mechanical performance when compared to our prior coil design and prototypes we tested, with the hottest components under 27 °C, the electrical resistance at 7.6 mΩ, and the inductance under 43 µH during regular operation. Additionally, the coil body and water distribution manifold has reduced tensile stress, which is a significant improvement. The new cooling system eliminates leaks, reduces tension, and has simplified plumbing, with only one inlet and one outlet, improving machinability.
This coil is also very reproducible, with many of the components, including the coil annuli, copper edge pieces, silicone gaskets, and polyester spacers being able to be produced in a standard machine shop with a laser cutter and a CNC or Waterjet. The water distribution manifold, tapped base plate, bus bars, and bus bar connectors needed to be machined externally, but these production costs were in total well in the budget of a standard lab.
Overall, this design details a low cost, state of the art, thermally stable, and machinable electromagnet that should provide stable fields for cold atom experiments.

VI. ACKNOWLEDGEMENTS

We would like to acknowledge Shaozhen Yang and the De-Mille Lab for guidance on the design and construction of this Bitter coil, the UChicago MRSEC for use of its facilities, and the NSF and U.S. Air Force Office of Scientific Research for funding.

VII. CITATIONS

1T. Lompe, Efimov Physics in a three-component Fermi gas, PhD dissertation, Ruperto-Carola University of Heidelberg, Combined Faculties of the Natural Sciences and Mathematics (2011), a full PHDTHESIS entry.
2S. Jochim, Bose-Einstein Condensation of Molecules, PhD dissertation, University of Innsbruck, Department of Physics (2004), a full PHDTHESIS en-

try.
3D. O. Sabulsky, C. V. Parker, N. D. Gemelke, and C. Chin, Review of Scientific Instruments 84, 104706 (2013).
4F. Bitter, Review of Scientific Instruments 7, 482 (1936).
5S. Yang and D. DeMille, .
6T. Luan, T. Zhou, X. Chen, and Z. Ma, Review of Scientific Instruments 85, 024701 (2014).
7
J. L. Siegel, D. S. Barker, J. A. Fedchak, J. Scherschligt, and S. Eckel, Review of Scientific Instruments 92, 033201 (2021).
